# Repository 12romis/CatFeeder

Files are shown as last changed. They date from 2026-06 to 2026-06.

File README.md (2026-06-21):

# Cat Feeder — ESP32-C3 automatic feeder

Automatic dry food dispenser. An ESP32-C3 SuperMini drives a 28BYJ-48 stepper motor
through a ULN2003 module, turning a 3D-printed auger screw that dispenses food pellets.
Feeding is triggered by a time schedule or by a physical button press.
The device runs from a single 18650 cell and sleeps between events.

---

## Hardware

| Ref | Component | Notes |
|-----|---|---|
| U2 | ESP32-C3 SuperMini | MCU + BLE 5.0 |
| U1 | TP4056 module | 18650 charging + protection |
| U3 | AP3602A boost module | 5 V rail for motor |
| M1 | ULN2003 driver module | stepper driver |
| SM1 | 28BYJ-48 stepper | auger drive |
| BT1 | 18650 Li-Ion cell | main power source |
| SW1 | Momentary push button | manual feed / wake |
| D1 | LED | status indicator |
| R1 | 220 Ω | LED current limit |
| C1 | 100 nF | power decoupling |
| C2 | 1000 µF | motor current buffer |

### Wiring

See schematic in [`schema/KiCad/cat_feeder.pdf`](schema/KiCad/cat_feeder.pdf)
or open the KiCad project at [`schema/KiCad/CatFeeder.kicad_sch`](schema/KiCad/CatFeeder.kicad_sch).

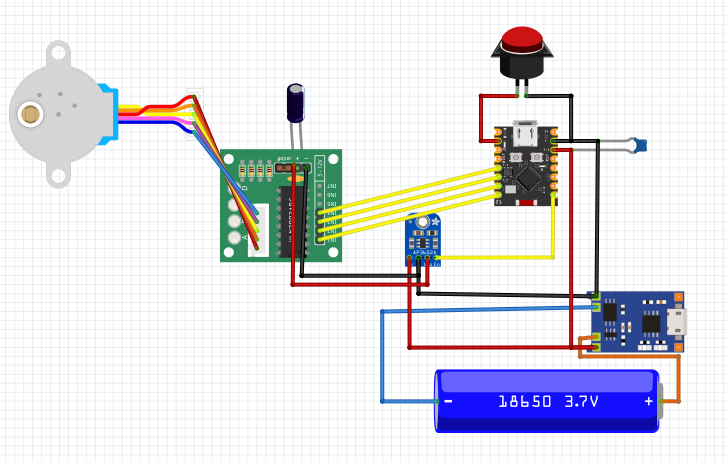
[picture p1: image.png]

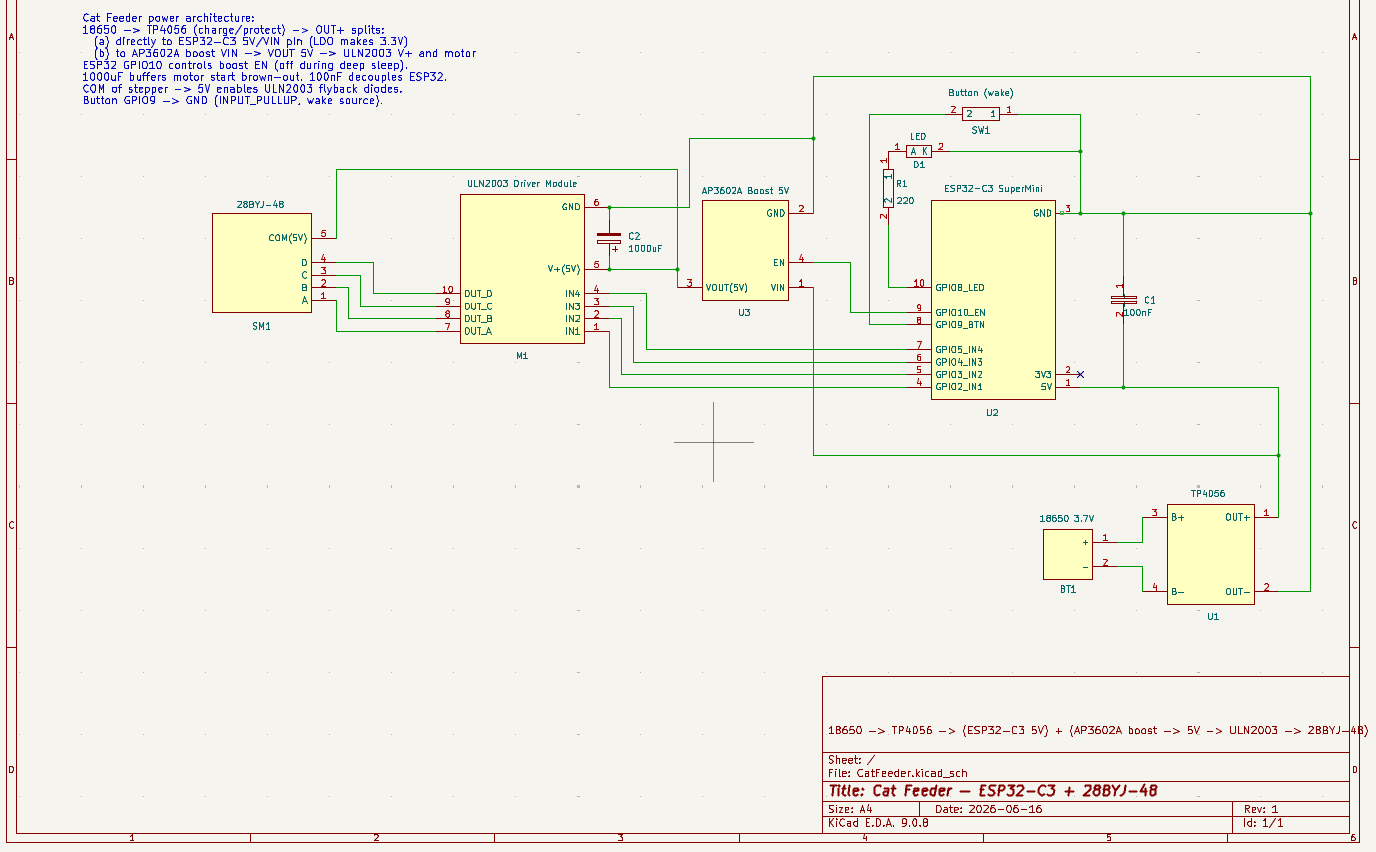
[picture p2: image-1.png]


**Pin map (ESP32-C3 SuperMini):**

| GPIO | Connects to | Direction |
|---|---|---|
| 2 | ULN2003 IN1 | OUT |
| 3 | ULN2003 IN2 | OUT |
| 4 | ULN2003 IN3 | OUT |
| 5 | ULN2003 IN4 | OUT |
| 8 | LED via 220 Ω to GND | OUT |
| 9 | Button to GND (INPUT\_PULLUP) | IN / wake |
| 10 | AP3602A boost EN | OUT |

Power path: `18650 → TP4056 → ESP32-C3 VIN` (always on)
and `18650 → TP4056 → AP3602A VIN → 5 V → ULN2003 + motor` (switched via GPIO 10).

---

## Software setup

### Requirements

- [VS Code](https://code.visualstudio.com/) with the
  [PlatformIO IDE](https://platformio.org/install/ide?install=vscode) extension
- USB cable (the C3 SuperMini uses native USB — port appears as `/dev/ttyACM0` on Linux)

### Build and flash

1. Open the **`CatFeeder/`** folder in VS Code (it is the PlatformIO project root).
2. Select the environment:
   - `c3` — ESP32-C3 SuperMini (production target)
   - `s3` — ESP32-S3 DevKitC-1 (breadboard test; same GPIO numbers)
3. Click **Upload** in the PlatformIO toolbar, or run:

```bash
pio run -e c3 --target upload
```

4. Open the Serial Monitor at **115200 baud**:

```bash
pio device monitor -e c3
```

> **Flash mode on C3 SuperMini:** if the board doesn't enter download mode automatically,
> hold **BOOT (GPIO 9)** while pressing **RESET**, then release RESET.

---

## First-run configuration via Serial console

All configuration is done by typing commands in the PlatformIO Serial Monitor
(line ending: `\n` or `\r\n`).

### 1. Configure Wi-Fi for automatic time sync (one-time setup)

The device has no RTC chip. On every cold boot (power-on after battery removed or
discharged) it connects to Wi-Fi, fetches UTC time from NTP, then immediately
disconnects. Wi-Fi is **never used after deep-sleep wakes** — only on cold boot.

```
WIFI_SSID MyNetwork
WIFI_PASS mypassword
```

Credentials are saved to flash and never need to be entered again.
If Wi-Fi is unavailable, the device falls back to manual time entry:

```
SET_TIME 1750420800
```

Get the current Unix epoch in your terminal:

```bash
date +%s
```

### 2. Set the feeding schedule

Times are in **UTC**. Up to 8 entries, space-separated.

```
SCHED 07:00 18:30
```

The schedule is saved to flash (NVS) and survives power-off.

Between scheduled feeds the device is in deep sleep. It wakes automatically at each
scheduled time, runs the motor, then sleeps until the next entry.

**Scheduled feed limits** (config.h):

| Limit | Default | Description |
|---|---|---|
| `MAX_PORTIONS_PER_DAY` | 4 | Max scheduled feeds per day; extras are skipped |
| `MIN_INTERVAL_SEC` | 1800 s | Min gap between scheduled feeds (30 min) |

These limits apply **only to the schedule**. Button press and `FEED` serial command
are always allowed regardless of how recently the motor ran.

### 3. Calibrate portion size

Portion size is defined in **stepper steps**, not time. Calibrate by weighing:

```
CAL 512       ← run motor 512 steps; weigh the dispensed food
CAL 768       ← try a different value
SAVE          ← commit the chosen step count to flash
```

Repeat `CAL` until the dispensed amount matches the desired portion weight.
`SAVE` must be sent explicitly — until then the new value is not persisted.

### 4. Verify

```
STATUS        ← show time, steps, portionsToday, schedule with next feed countdown
FEED          ← manual feed (no limits)
RESET_DAY     ← zero portionsToday and lastFeedEpoch (for testing)
```

---

## All Serial commands

| Command | Description |
|---|---|
| `WIFI_SSID <ssid>` | Save Wi-Fi network name to flash |
| `WIFI_PASS <pass>` | Save Wi-Fi password to flash |
| `WIFI_SYNC` | Connect and sync time via NTP now |
| `SET_TIME <epoch>` | Set wall clock manually (Unix seconds UTC) |
| `SCHED HH:MM [HH:MM ...]` | Set feeding schedule (UTC, up to 8 entries) |
| `CAL <steps>` | Run motor N steps without counting as a feed |
| `SAVE` | Save the last CAL step count to flash |
| `FEED` | Dispense one portion (no limits) |
| `STATUS` | Print current device state incl. schedule and Wi-Fi SSID |
| `RESET_DAY` | Zero portionsToday and lastFeedEpoch |

---

## Button behaviour

| Press | Action |
|---|---|
| Short press | Dispense one portion |
| Double click (gap < 300 ms) | Dispense two portions |
| Long press ≥ 2 s | Enter deep sleep immediately without feeding |

---

## Power notes

- The device enters deep sleep between feeds. Wake sources: button or RTC timer.
- The 5 V motor rail (boost converter) is switched on only during a dose, then cut.
- Always-on current in deep sleep: ~50–100 µA (ESP32-C3 + LDO quiescent).
- Expected battery life on 3000 mAh 18650 with 4 feeds/day: **several months**.

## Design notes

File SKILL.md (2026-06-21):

---
name: cat-feeder-firmware
description: Context and engineering rules for writing ESP32-C3 firmware for an automatic BLE cat feeder with an auger-screw dosing mechanism driven by a 28BYJ-48 stepper. Use whenever generating, reviewing, or refactoring firmware for this project — dosing logic, BLE GATT server, deep-sleep/wake handling, scheduling, or power management.
---

# Cat Feeder Firmware — Project Context

Automatic cat feeder. An ESP32-C3 drives a 28BYJ-48 stepper through a ULN2003
module turning a 3D-printed auger screw that dispenses dry food. Two feeding modes:
(1) time-based schedule, (2) on-demand portion triggered from a phone app over BLE.
The device runs from an 18650 cell and must be power-frugal (deep sleep between events).

The agent writing code for this project MUST read and honor everything below before
producing firmware. Treat the hardware pin map and the safety rules as non-negotiable.

---

## 1. Target & toolchain

- **MCU:** ESP32-C3 SuperMini (RISC-V single core, BLE 5.0, Wi-Fi unused).
- **Framework:** Arduino-ESP32 under **PlatformIO** (the developer uses PlatformIO on
  Kubuntu with USB Serial/JTAG debugging — pioarduino flavor acceptable).
- **BLE stack:** **NimBLE-Arduino** (NOT the default Bluedroid — NimBLE uses far less
  RAM/flash and is the right choice on a C3).
- **Language:** C++ (Arduino style), readable, commented. Non-blocking patterns
  preferred; avoid long `delay()` in the main path.
- Developer is fluent in embedded C/C++, FreeRTOS, PlatformIO. Do NOT over-explain
  basics. Be concise and technically precise. Communicate in Ukrainian when chatting,
  code comments may be Ukrainian or English (developer reads both).

## 2. Hardware pin map (authoritative — do not change without being asked)

| ESP32-C3 GPIO | Connects to | Notes |
|---|---|---|
| GPIO2 | ULN2003 IN1 | stepper phase |
| GPIO3 | ULN2003 IN2 | stepper phase |
| GPIO4 | ULN2003 IN3 | stepper phase |
| GPIO5 | ULN2003 IN4 | stepper phase |
| GPIO9 | Push button | wake source; INPUT_PULLUP, button to GND |
| GPIO10 | Boost converter EN | drive HIGH to enable 5V boost, LOW to kill motor rail in sleep |
| GPIO8 | Status LED (via 220Ω) | optional indicator |
| 5V / VIN | +5V from boost / battery | board LDO makes 3.3V |
| 3V3 | unused (no-connect) | internal LDO output |

- Button is the ONLY wake source. On ESP32-C3 deep-sleep wake uses GPIO with RTC
  capability — verify GPIO9 supports `esp_deep_sleep_enable_gpio_wakeup` (C3 uses
  GPIO wakeup, not ext0/ext1 like classic ESP32). If GPIO9 is a strapping/BOOT pin
  on this board variant, flag it and propose an alternative RTC-capable GPIO.

## 3. Power architecture (drives the sleep strategy)

```
18650 (3.0–4.2V) → TP4056 (charge + protect) → OUT+ splits:
   (a) → ESP32-C3 5V/VIN pin directly  (LDO makes 3.3V; C3 tolerates 3.0–4.2V on VIN)
   (b) → AP3602A boost VIN → VOUT 5V → ULN2003 V+ and 28BYJ-48 motor
```

- ESP32 is always powered from the battery (cannot be hard-cut, it must run BLE/RTC).
- The **motor rail (boost) is switchable** via GPIO10 → boost EN.
- **Autonomy is dominated by quiescent current, not battery capacity.** In deep sleep
  the C3 draws ~tens of µA; an always-on BLE advertise draws ~100 mA. The whole design
  intent is: sleep most of the time, wake briefly.

## 4. Core firmware behavior (functional spec)

### 4.1 Dosing — BY STEPS, never by time
- Portion size is defined in **stepper steps**, e.g. `STEPS_PER_PORTION`, calibrated by
  weighing dispensed food. NEVER dose by "run motor for N milliseconds" — speed drifts
  with battery voltage and load, ruining repeatability.
- 28BYJ-48: 2048 steps/rev (full-step, 64:1 gearbox). Keep RPM modest (~12) so the
  auger doesn't stall under load.
- **Anti-jam reverse:** during a dose, periodically step backward a small amount then
  forward to break food bridging in the auger. Make reverse-steps and cycle count
  constants.

### 4.2 De-energize coils after every move (CRITICAL)
- After any dose, set IN1–IN4 LOW. A stationary 28BYJ-48 with a coil energized heats up
  and wastes current — this can dominate the whole power budget. Always release coils.

### 4.3 Boost EN management around sleep (CRITICAL)
- Before entering deep sleep: release coils, then drive GPIO10 LOW (kill motor rail).
- On wake / before a dose: drive GPIO10 HIGH, allow a few ms for boost to stabilize,
  then move the motor.

### 4.4 Two feeding modes
- **Schedule:** feed at configured times (hour:minute). No RTC chip — time is obtained
  via **Wi-Fi NTP on cold boot** (see §4.7). After a deep-sleep wake the time is already
  known from RTC_DATA_ATTR; Wi-Fi is never activated on wake. If NTP fails (no
  credentials or no AP), time can be set manually with `SET_TIME <epoch>` over Serial.
  Until time is known, schedule mode is "pending" — no scheduled feeds fire.
- **Manual:** button press OR Serial `FEED` → one portion, no limits.

### 4.5 Overfeed protection (safety — must be enforced for BOTH modes)
- Minimum interval between portions (`MIN_INTERVAL`).
- Maximum portions per day (`MAX_PORTIONS_PER_DAY`).
- A blocked attempt must NOT dispense and should report a reason over BLE / serial.

### 4.6 Wake / sleep flow
- Wake sources: button (GPIO9) and RTC timer for the next scheduled feed.
- Pattern: wake → perform any due feed → release coils → boost EN LOW → compute next
  wake time → deep sleep.
- Serial config window: device stays awake for `SERIAL_STAY_AWAKE_SEC` (60 s) after the
  last Serial command, then sleeps. This allows typing SCHED/CAL/SAVE after first boot.

### 4.7 Wi-Fi NTP time sync
- **Cold boot only**: on `ESP_SLEEP_WAKEUP_UNDEFINED`, the device connects to the
  configured AP, fetches UTC epoch from `pool.ntp.org`, calls `scheduleSetTime()`, then
  disconnects and turns Wi-Fi off (`WiFi.mode(WIFI_OFF)`).
- **Deep-sleep wakes**: Wi-Fi is never activated. Time is preserved in `RTC_DATA_ATTR`
  across deep sleep cycles and does not need re-syncing until the next full power-off.
- **Credentials**: stored in NVS namespace `"wifi"` (keys `ssid`, `pass`) via Serial
  commands `WIFI_SSID` / `WIFI_PASS`. One-time setup, survives battery replacement.
- **Fallback**: if Wi-Fi unavailable or not configured, device waits for `SET_TIME`
  via Serial. Manual command `WIFI_SYNC` forces a sync at any time.
- **Timeouts**: `WIFI_CONNECT_MS` (10 s) for association, `WIFI_NTP_MS` (5 s) for
  first NTP response (config.h).

## 5. BLE GATT design (NimBLE)

- Role: GATT **server** (peripheral). Phone is the client.
- Suggested single custom service with these characteristics (use 128-bit UUIDs):
  - **Command** (write): opcodes — `FEED_NOW`, `SET_SCHEDULE`, `SET_TIME` (epoch),
    `SET_PORTION_STEPS` (calibration), `GET_STATUS`.
  - **Status/Notify** (read+notify): last result, portions today, next feed time,
    battery/raw VIN if measured, error/blocked reasons.
- Keep the protocol small and binary or compact JSON; document the byte/field layout in
  comments. Validate every incoming write (length, range) before acting.
- On connect: expect a `SET_TIME` sync; until time is known, schedule mode is "pending".

## 6. Code structure expectations

- Separate concerns into modules/files: `motor` (stepper + anti-jam + release),
  `dosing` (portion logic + safety limits), `schedule`, `ble` (GATT server),
  `power` (boost EN + deep sleep entry/exit), `config` (pins + tunables in one header).
- All tunables (pins, STEPS_PER_PORTION, RPM, MIN_INTERVAL, MAX_PORTIONS_PER_DAY,
  anti-jam params, BLE window length) live in a single `config.h` — no magic numbers
  scattered in logic.
- Persist calibration + schedule + portionsToday across deep sleep. Deep sleep wipes
  RAM except RTC memory → use `RTC_DATA_ATTR` for small state, or NVS (Preferences)
  for settings that must survive full power loss.
- Provide a clean build that compiles under PlatformIO with the NimBLE dependency
  declared in `platformio.ini`.

## 7. Hard rules (the agent must not violate)

1. Dose by steps, never by time.
2. Always release stepper coils after moving.
3. Kill boost EN (GPIO10 LOW) before deep sleep; raise it before driving the motor.
4. Enforce overfeed limits on every dispense path (button, BLE, schedule).
5. Do not hard-cut ESP32 power; only the motor rail is switchable.
6. Use NimBLE, not Bluedroid.
7. Keep 28BYJ-48 at 5V — never 12V (would destroy the motor).
8. Validate all BLE inputs before acting.
9. Keep blocking time minimal; never `delay()` for seconds in the loop.
10. Match the pin map in section 2 exactly.

## 8. Known constraints / gotchas

- No RTC chip: wall-clock relies on BLE time sync; handle "time unknown after reset".
- 28BYJ-48 is weak (~34 mN·m); auger is Ø24 screw in a Ø25 tube, ~60 mm, horizontal,
  pellet size 8–9 mm. If stalls occur, the fix is mechanical/anti-jam, not more current.
- ULN2003 module already wires COM to its V+ (flyback diodes handled on-board) — no
  extra diode needed in firmware reasoning.
- Brown-out risk when the motor starts and pulls through the boost from the same cell;
  a 1000µF bulk cap buffers it. Firmware should still raise boost EN and settle before
  stepping to reduce the transient.

---

## 9. Repository layout

```
CatFeeder/                      ← root = PlatformIO project (open this in VS Code)
├── SKILL.md                    ← this file (agent context + rules)
├── CLAUDE.md                   ← auto-loaded by Claude Code; sources this file
├── platformio.ini              ← PlatformIO build config (envs: c3, s3)
├── include/
│   └── config.h                ← ALL tunables and pin map here
├── src/
│   ├── main.cpp
│   ├── motor.cpp / motor.h
│   ├── dosing.cpp / dosing.h
│   ├── schedule.cpp / schedule.h
│   ├── ble.cpp / ble.h
│   ├── wifi_time.cpp / wifi_time.h
│   └── power.cpp / power.h
├── schema/
│   ├── CatFeederSchematic.fzz  ← Fritzing (legacy/illustration)
│   └── KiCad/                  ← KiCad 9.0 project (authoritative schematic)
│       ├── CatFeeder.kicad_sch ← full schematic (source of truth for connections)
│       ├── CatFeeder.kicad_pcb ← PCB layout
│       ├── cat_feeder.csv      ← BOM
│       ├── cat_feeder.pdf      ← rendered schematic PDF
│       └── cat_feeder.net      ← netlist
├── .pio/                       ← build artifacts (git-ignored)
└── .vscode/                    ← auto-generated by PlatformIO IDE (git-ignored)
```

**Hardware stage:** currently breadboard; later all boards and components will sit in
3D-printed slots and be connected by wires. PCB layout in KiCad is prepared but not yet
manufactured.

## 10. PlatformIO build setup (expected platformio.ini)

```ini
[env:esp32-c3-supermini]
platform    = espressif32
board       = esp32-c3-devkitm-1   ; closest upstream board; override pins in config.h
framework   = arduino
monitor_speed = 115200
upload_speed  = 921600

lib_deps =
    h2zero/NimBLE-Arduino @ ^1.4.3  ; use latest stable 1.x; check for breaking changes in 2.x

build_flags =
    -DCORE_DEBUG_LEVEL=3             ; verbose log in debug builds; set to 0 for release
    -DCONFIG_BT_NIMBLE_ROLE_PERIPHERAL=1

; USB Serial/JTAG on ESP32-C3 — no extra UART chip needed
upload_protocol = esptool
monitor_port    = /dev/ttyACM0      ; C3 SuperMini shows up as ACM, not USB0
```

**Note:** ESP32-C3 SuperMini uses native USB-serial (CDC over USB), so the port is
`/dev/ttyACMx`, not `/dev/ttyUSBx`. To flash after deep sleep you may need to hold BOOT
(GPIO9) while pressing RESET to enter download mode.

## 11. Calibration via Serial console

`STEPS_PER_PORTION` must be found empirically by weighing dispensed food. No mobile app
is planned in the near term; calibration is done over the USB Serial monitor in PlatformIO.

**Calibration flow (Serial command `CAL <steps>`):**

1. User sends `CAL <steps>` (e.g. `CAL 512`) over Serial.
2. Firmware runs exactly `<steps>` steps (bypasses overfeed guard — calibration mode only).
3. User weighs the dispensed food and repeats until the desired gram-per-portion is reached.
4. User sends `SAVE` to commit the chosen step count to NVS as `stepsPerPortion`.
5. Firmware echoes back the saved value.

**Implementation notes:**
- Parse Serial input in `loop()` — non-blocking, read until `\n`.
- `CAL` mode flag should prevent the step count from updating `portionsToday` or
  triggering the overfeed limiter.
- Other Serial commands worth supporting: `STATUS` (dump current state), `FEED` (manual
  portion, respects limits), `RESET_DAY` (zero portionsToday for testing).

## 12. BLE GATT — minimal working set

No mobile app is planned now (may appear later in a separate repository). The BLE GATT
server should still be implemented so the device is future-ready. Keep characteristics
generic: **Command** (write) and **Status** (read + notify). The exact binary protocol
can be defined when the app is started. For now, BLE is useful for:
- `FEED_NOW` command from any BLE scanner app (e.g. nRF Connect) during development.
- `SET_TIME` to sync epoch for schedule testing without a custom app.

## 13. Debugging & serial output

- Use `Serial.begin(115200)` in `setup()` — USB CDC on C3 is stable.
- Use `ESP_LOGx` macros (LOGD/LOGI/LOGE) with a module tag, e.g. `ESP_LOGI("motor", "steps=%d", steps)` — controlled by `CORE_DEBUG_LEVEL` build flag, zero overhead in release.
- During development keep `CORE_DEBUG_LEVEL=3`; set to `0` for battery-life measurements.
- To measure actual deep-sleep current: disconnect USB, power from bench supply through a shunt; expect ~50–100 µA (C3 + quiescent LDO). If it's mA-range, a coil is still energised or boost EN is HIGH.

## 14. State persistence across deep sleep

| Data | Size | Storage | Survives power loss? |
|---|---|---|---|
| `portionsToday`, `lastFeedTime`, `timeKnown` flag | tiny | `RTC_DATA_ATTR` | no (only deep sleep) |
| schedule (times), `stepsPerPortion`, `minInterval`, `maxPortions` | ~dozens bytes | NVS (`Preferences`) | yes |
| wall-clock epoch at last sync | uint32 | `RTC_DATA_ATTR` + NVS | NVS copy for cold boot |

On cold boot (power-on, not deep-sleep wake): restore settings from NVS; `timeKnown = false`
until next BLE `SET_TIME`. Schedule feeds are deferred until time is synced.

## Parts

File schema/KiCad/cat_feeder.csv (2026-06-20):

Reference | Qty | Value | DNP | Exclude from BOM | Exclude from Board | Footprint | Datasheet
BT1 | 1 | 18650 3.7V
C1 | 1 | 100nF
C2 | 1 | 1000uF |  |  |  |  | ~
D1 | 1 | LED
M1 | 1 | ULN2003 Driver Module
R1 | 1 | 220
SM1 | 1 | 28BYJ-48
SW1 | 1 | Button (wake)
U1 | 1 | TP4056
U2 | 1 | ESP32-C3 SuperMini
U3 | 1 | AP3602A Boost 5V

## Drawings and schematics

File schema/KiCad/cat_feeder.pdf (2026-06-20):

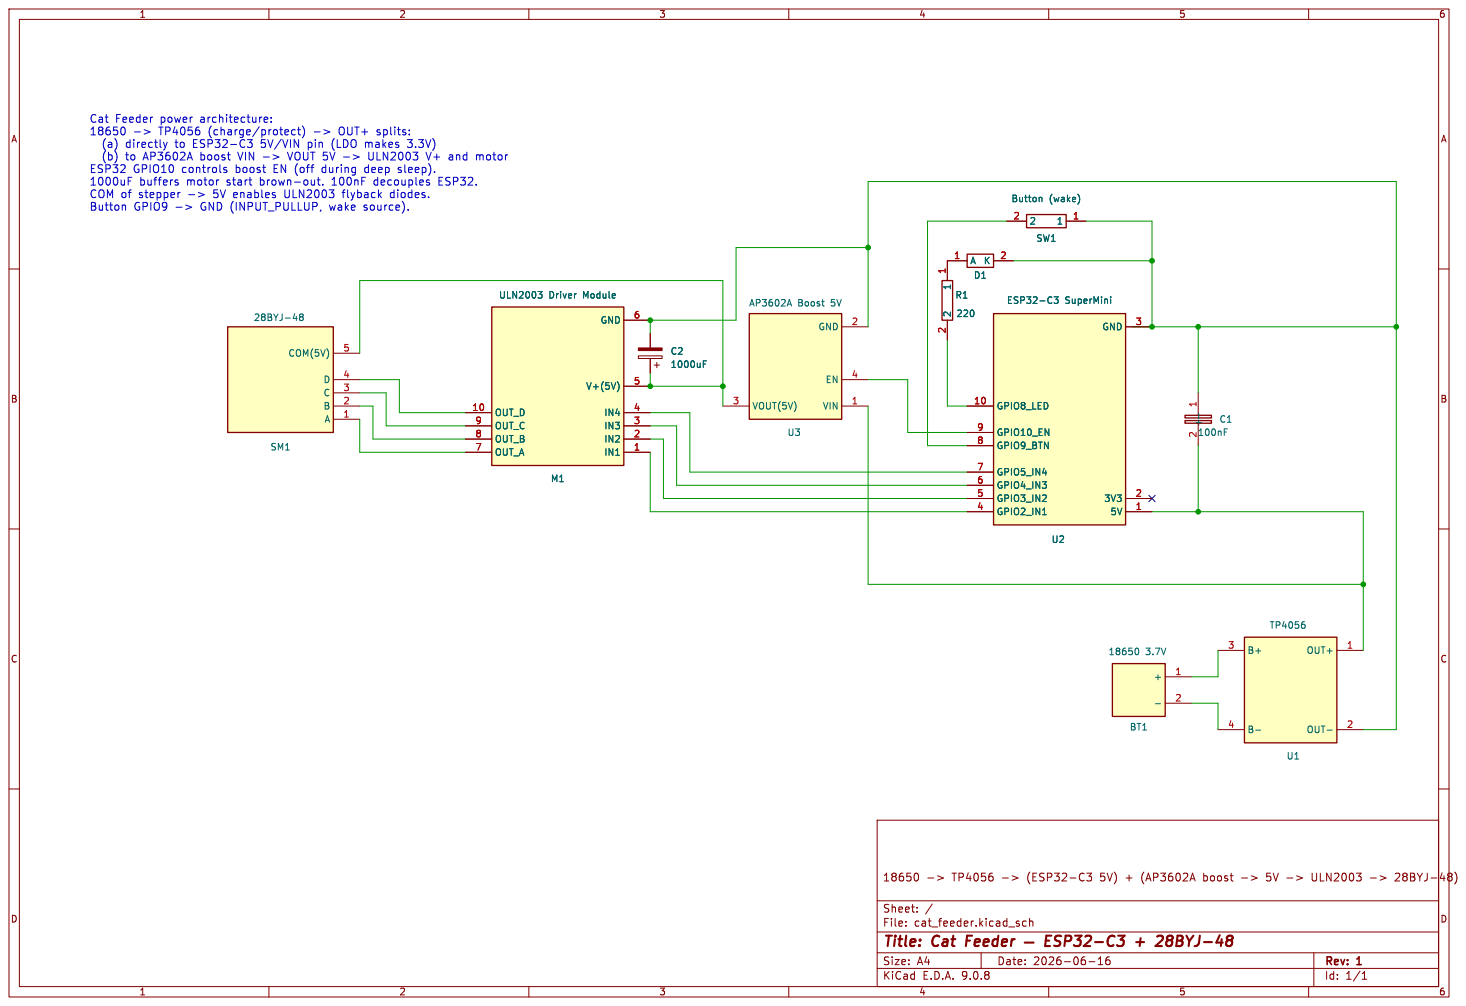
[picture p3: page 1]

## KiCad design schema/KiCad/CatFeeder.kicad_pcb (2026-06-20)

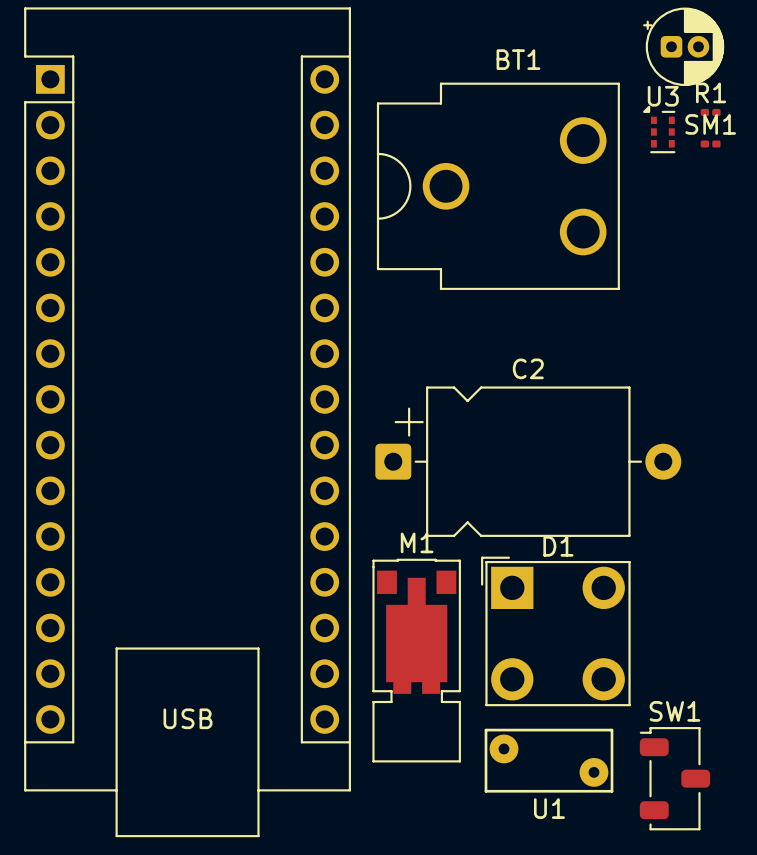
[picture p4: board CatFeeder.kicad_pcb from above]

Board: 2 copper layers, 11 parts (0 on the bottom side), 9 nets, no tracks yet.

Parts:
BT1: 18650 3.7V; BatteryClip_Keystone_54_D16-19mm
C1: 100nF; CP_Radial_D4.0mm_P1.50mm
C2: 1000uF; CP_Axial_L11.0mm_D8.0mm_P15.00mm_Horizontal
D1: LED; LED_BL-FL7680RGB
M1: ULN2003 Driver Module; Vybronics_VZ30C1T8219732L
R1: 220; R_0201_0603Metric
SM1: 28BYJ-48; R_0201_0603Metric
SW1: Button (wake); Nidec_Copal_CAS-120A
U1: TP4056; RV_Disc_D7mm_W3.4mm_P5mm
U2: ESP32-C3 SuperMini; Arduino_Nano
U3: AP3602A Boost 5V; Anaren_0805_2012Metric-6

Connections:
unnamed: C1.1 (+), C2.2, D1.2 (K), SW1.1, U1.2 (OUT-), U2.3 (GND), U3.2 (GND)
unnamed: C1.2 (-), U1.1 (OUT+), U2.1 (5V), U3.1 (VIN)
unnamed: D1.1 (A), R1.1
unnamed: M1.1 (IN1), U2.4 (GPIO2_IN1)
unnamed: M1.2 (IN2), U2.5 (GPIO3_IN2)
unnamed: C2.1, U3.3 (VOUT(5V))
unnamed: R1.2, U2.10 (GPIO8_LED)
unnamed: SW1.2, U2.8 (GPIO9_BTN)
unnamed: U2.9 (GPIO10_EN), U3.4 (EN)

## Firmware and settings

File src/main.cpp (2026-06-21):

#include <Arduino.h>
#include <esp_sleep.h>
#include "config.h"
#include "power.h"
#include "motor.h"
#include "dosing.h"
#include "schedule.h"
#include "wifi_time.h"
#if BLE_ENABLED
#include "ble.h"
#endif

// ── Button polling while the device is awake ───────────────────────────────
// Deep sleep wakeup handles the button on wake-up; this handles it during the
// active window (Serial config session, BLE window, etc.).

static uint32_t btnPressMs   = 0;
static uint32_t btnReleaseMs = 0;
static bool     btnHeld      = false;
static uint8_t  clickCount   = 0;

static void buttonTick() {
    bool low = (digitalRead(PIN_BUTTON) == LOW);
    uint32_t now = millis();

    if (low && !btnHeld) {
        btnPressMs = now;
        btnHeld    = true;
    } else if (!low && btnHeld) {
        uint32_t held = now - btnPressMs;
        btnHeld = false;
        if (held < DEBOUNCE_MS) return;  // noise — ignore

        if (held >= LONG_PRESS_MS) {
            clickCount = 0;
            ESP_LOGI("main", "long press while awake — sleep");
            powerSleep(scheduleNextWakeSec());
            return;
        }

        clickCount++;
        btnReleaseMs = now;
    }

    // Dispatch once double-click window expires and button is released
    if (clickCount > 0 && !btnHeld && (now - btnReleaseMs) >= DOUBLE_CLICK_MS) {
        if (clickCount >= 2) {
            ESP_LOGI("main", "double click — double portion");
            dosingFeed(FeedMode::BUTTON);
            dosingFeed(FeedMode::BUTTON);
        } else {
            FeedResult r = dosingFeed(FeedMode::BUTTON);
            const char* msg[] = {"OK", "BLOCKED_INTERVAL", "BLOCKED_DAILY", "NO_TIME"};
            ESP_LOGI("main", "button feed: %s", msg[(uint8_t)r]);
        }
        clickCount = 0;
    }
}

void setup() {
    Serial.begin(SERIAL_BAUD);

    powerInit();    // GPIO10 (boost) LOW, LED LOW, button INPUT_PULLUP
    motorInit();    // stepper pins OUTPUT LOW (coils released)
    scheduleInit(); // load schedule + time state first — dosingInit() depends on scheduleNow()
    dosingInit();   // load stepsPerPortion from NVS
#if BLE_ENABLED
    bleInit();      // init NimBLE GATT server (not advertising yet)
#endif

    auto cause = esp_sleep_get_wakeup_cause();

    // WAKEUP_CAUSE_BUTTON = ESP_SLEEP_WAKEUP_GPIO (C3) or ESP_SLEEP_WAKEUP_EXT1 (S3)
    if (cause == WAKEUP_CAUSE_BUTTON) {
        ESP_LOGI("main", "woke by button");

        // Detect long press: button still held after setup() (~200 ms boot time).
        // Short press → already released → feed.
        // Long press → held LONG_PRESS_MS more → sleep without feeding.
        // Deadline prevents infinite spin on a shorted button contact.
        if (digitalRead(PIN_BUTTON) == LOW) {
            uint32_t holdStart = millis();
            uint32_t deadline  = holdStart + LONG_PRESS_MS + 5000;
            while (digitalRead(PIN_BUTTON) == LOW && millis() < deadline) delay(10);
            if (millis() - holdStart >= LONG_PRESS_MS) {
                ESP_LOGI("main", "long press — going to sleep");
                powerSleep(scheduleNextWakeSec());
                // no return — deep sleep starts inside
            }
        }

        FeedResult r = dosingFeed(FeedMode::BUTTON);
        const char* msg[] = {"OK", "BLOCKED_INTERVAL", "BLOCKED_DAILY", "NO_TIME"};
        ESP_LOGI("main", "button feed: %s", msg[(uint8_t)r]);

    } else if (cause == ESP_SLEEP_WAKEUP_TIMER) {
        // Scheduled feed timer — run schedule check, then go back to sleep
        ESP_LOGI("main", "woke by timer");
        scheduleCheck();

    } else {
        // Cold boot — try NTP sync via Wi-Fi; fall back to SET_TIME via Serial
        ESP_LOGI("main", "cold boot");
        bool synced = wifiSyncTime();
        if (!synced) {
            ESP_LOGW("main", "NTP failed — waiting for SET_TIME or WIFI_SSID/WIFI_PASS");
        }
    }
}

void loop() {
    dosingProcessSerial();  // handle CAL/SAVE/FEED/STATUS/RESET_DAY
    scheduleCheck();        // fire any due feed entries
    buttonTick();           // poll button while awake (deep sleep handles it on wake)
    // bleTick();              // close BLE window when BLE_WINDOW_SEC expires
    powerTick();            // sleep when BLE is closed and no work is pending
}

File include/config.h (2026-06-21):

#pragma once

// ============================================================
// Pin map — same GPIO numbers on both targets (verified safe)
// GPIO2-5 are freely usable on both C3 and S3 DevKitC-1.
// S3 strapping pins to avoid: GPIO0 (BOOT), GPIO3, GPIO45, GPIO46.
// GPIO3 is a strapping pin on S3 but safe to use as OUTPUT after boot.
// ============================================================
#if defined(TARGET_C3)
  #define PIN_STEPPER_IN1   2
  #define PIN_STEPPER_IN2   3
  #define PIN_STEPPER_IN3   4
  #define PIN_STEPPER_IN4   5
  #define PIN_BUTTON        9   // INPUT_PULLUP, button to GND; GPIO wakeup source
  #define PIN_BOOST_EN      10  // HIGH = boost on, LOW = motor rail off
  #define PIN_LED           8   // status LED via 220R to GND
#elif defined(TARGET_S3)
  // S3 DevKitC-1 breadboard test — same GPIO numbers as C3 (matches schematic wiring).
  // GPIO48 = onboard RGB LED on DevKitC-1 — avoid
  // GPIO39–42 = JTAG, GPIO0 = BOOT, GPIO19/20 = USB D±  — all avoided
  #define PIN_STEPPER_IN1   3
  #define PIN_STEPPER_IN2   4
  #define PIN_STEPPER_IN3   5
  #define PIN_STEPPER_IN4   6
  #define PIN_BUTTON        9
  #define PIN_BOOST_EN      10
  #define PIN_LED           8
#else
  #error "Build target not defined. Use -DTARGET_C3 or -DTARGET_S3"
#endif

// ============================================================
// Stepper tunables
// ============================================================
#define STEPS_PER_REV           2048    // 28BYJ-48 full-step, 64:1 gearbox
#define STEPS_PER_PORTION       512     // initial value — calibrate with CAL command
#define STEPPER_RPM             12
// Microseconds per step derived from RPM:
#define STEPPER_STEP_US         ((60UL * 1000000UL) / ((uint32_t)STEPS_PER_REV * STEPPER_RPM))

// Anti-jam: briefly reverse every N forward steps
#define ANTIJAM_CYCLE_EVERY     256     // forward steps between reverse pulses
#define ANTIJAM_REVERSE_STEPS   32      // steps backward per anti-jam pulse

// ============================================================
// Overfeed safety limits
// ============================================================
#define MIN_INTERVAL_SEC        (30 * 60)   // 30 min between portions
#define MAX_PORTIONS_PER_DAY    4

// ============================================================
// BLE
// ============================================================
#define BLE_ENABLED             0           // set to 1 when BLE is needed
#define BLE_DEVICE_NAME         "CatFeeder"
#define BLE_WINDOW_SEC          60          // advertising window after button press

// ============================================================
// Power / button
// ============================================================
#define BOOST_SETTLE_MS         5           // settle time after boost EN before stepping
#define LONG_PRESS_MS           2000        // hold duration to enter sleep without feeding

// Wakeup cause constant for the button — platform-specific.
// C3: GPIO wakeup (esp_deep_sleep_enable_gpio_wakeup).
// S3: EXT1 wakeup (esp_sleep_enable_ext1_wakeup).
#if defined(TARGET_C3)
#define WAKEUP_CAUSE_BUTTON  ESP_SLEEP_WAKEUP_GPIO
#else
#define WAKEUP_CAUSE_BUTTON  ESP_SLEEP_WAKEUP_EXT1
#endif

// ============================================================
// Wi-Fi NTP time sync (cold boot only)
// ============================================================
#define WIFI_CONNECT_MS   10000           // max ms to associate with AP
#define WIFI_NTP_MS        5000           // max ms to receive first NTP response
#define NTP_SERVER1       "pool.ntp.org"
#define NTP_SERVER2       "time.google.com"

// ============================================================
// Serial
// ============================================================
#define SERIAL_BAUD             115200
// After any Serial command, stay awake this many seconds so the user can type more.
#define SERIAL_STAY_AWAKE_SEC   60
// Button debounce: presses shorter than this are ignored as noise.
#define DEBOUNCE_MS             50
// Max gap between two clicks to count as a double-click.
#define DOUBLE_CLICK_MS         300

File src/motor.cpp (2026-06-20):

#include <Arduino.h>
#include "motor.h"
#include "config.h"

// Double-coil full-step sequence for 28BYJ-48 (higher torque than wave-drive).
// Indexed by (currentPhase & 3).
static const uint8_t kStepTable[4][4] = {
    {1, 1, 0, 0},  // IN1 IN2 IN3 IN4
    {0, 1, 1, 0},
    {0, 0, 1, 1},
    {1, 0, 0, 1},
};

static const uint8_t kPins[4] = {
    PIN_STEPPER_IN1, PIN_STEPPER_IN2, PIN_STEPPER_IN3, PIN_STEPPER_IN4
};

static int8_t phase = 0;  // current step phase 0–3

static void applyPhase() {
    const uint8_t* row = kStepTable[phase & 3];
    for (int i = 0; i < 4; i++) digitalWrite(kPins[i], row[i]);
}

static void singleStep(int8_t dir) {
    phase = (phase + dir + 4) % 4;
    applyPhase();
    delayMicroseconds(STEPPER_STEP_US);
}

void motorInit() {
    for (int i = 0; i < 4; i++) {
        pinMode(kPins[i], OUTPUT);
        digitalWrite(kPins[i], LOW);
    }
}

void motorRelease() {
    for (int i = 0; i < 4; i++) digitalWrite(kPins[i], LOW);
}

void motorStep(int32_t steps, bool antiJam) {
    if (steps == 0) return;

    int8_t dir = (steps > 0) ? 1 : -1;
    int32_t remaining = (steps > 0) ? steps : -steps;
    int32_t sinceJam = 0;

    while (remaining-- > 0) {
        singleStep(dir);
        if (antiJam && dir == 1) {
            if (++sinceJam >= ANTIJAM_CYCLE_EVERY) {
                for (int r = 0; r < ANTIJAM_REVERSE_STEPS; r++) singleStep(-1);
                for (int r = 0; r < ANTIJAM_REVERSE_STEPS; r++) singleStep(1);
                sinceJam = 0;
            }
        }
    }
    motorRelease();
}

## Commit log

2026-06-20 Initial firmware scaffold for ESP32-C3 automatic cat feeder
    Hardware: ESP32-C3 SuperMini + 28BYJ-48 stepper via ULN2003, 18650 cell,
    AP3602A boost converter, TP4056 charger.
    Firmware: Arduino/PlatformIO, NimBLE-Arduino. Modules: motor (double-coil
    full-step + anti-jam), dosing (step-based portions, FeedMode, overfeed limits),
    schedule (RTC-free timekeeping via esp_rtc_get_time_us), power (deep sleep,
    boost EN switching), ble (GATT server skeleton). Serial console calibration
    (CAL/SAVE/SCHED/SET_TIME). Two PlatformIO envs: c3 (target) and s3 (test).
    [CatFeeder.kicad_pcb, CatFeeder.kicad_sch, CatFeederSchematic.fzz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]
2026-06-20 Fix broken schema links: CatFeeder/ → KiCad/ folder rename
2026-06-21 fixes after first run on s3 and breadboard
    [config.h, dosing.cpp, main.cpp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]
